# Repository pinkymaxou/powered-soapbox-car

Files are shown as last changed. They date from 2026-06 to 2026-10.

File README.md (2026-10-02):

# Powered Soapbox Car — 2-Seat Electric Kart for Kids




Project to build a **two-seat electric kart** for kids (~10 years old, 1.38–1.45 m), designed to be buildable with **basic tools** (drill, saw, wrenches) plus a **3D printer** for the gearboxes. Every choice is explained so you can adapt it to the materials you have on hand.

> **Note:** this kart is a **REVERSED tricycle**. The **2 REAR wheels are powered and independent** (one **12 V DC motor + gearbox + #35 chain per wheel**), sitting **under the bench**; **steering is done by the speed difference** between them (*differential / skid steer*) — **no steering wheel, no column, no linkage**. At the **front centre**, **one free 10″ caster** orients itself, with the battery in the nose over it → **3 wheels total**. ⚠️ The first version had this backwards (driven wheels at the front, caster at the rear, bench far from the driven axle) and it was **too unstable — 0.39 g**, held upright by the software turn limiter alone. A tricycle tips about the line from the **single** wheel to one of the **paired** wheels, so the usable half-track is `(distance CG→single wheel)/wheelbase`: putting the mass near the **paired axle** takes that from 45 % to 80 %. ⚠️ On **2026-08-10** the bench moved **6″ forward** and the axle **6″ back** — 12″ of separation — which gave back 78 mm of that: **61 %, a_tip 0.53 g**. That is still 1.4× the original tricycle — and since **2026-09-29 there is no software turn limiter at all** (the wheel sensors are gone; the owner's decision). In simulation a full-speed full turn at the default `duty_cap` 1.0 **tips the kart with one child sitting off-centre or with an adult aboard**; two children centred stay upright. `duty_cap` is the only lever — the numbers are in [§5](#5-critical-safety-points-child). The kart is a **two-seater** (two kids **side by side**) and **driven with a Bluetooth gamepad** ("arcade" mixing: one stick to go forward/back and to turn) — **no throttle pedal and no steering wheel**. Propulsion comes from the **2 rear motors**; there is **no** pedal crank and no chain.

## Table of contents

- [Overview (top view)](#overview-top-view)
- [At a glance](#at-a-glance) · [Why these choices](#why-these-choices)
- [1. Chassis dimensions](#1-chassis-dimensions)
- [2. Seat / controls position](#2-seat--controls-position)
- [3. Differential steering](#3-differential-steering-skid-steer) · [Driving: START arms, A drives](#driving-start-arms-a-drives)
- [4. Hardware & electronics](#4-hardware--electronics)
  - [Propulsion (2 rear motors)](#propulsion--2-rear-12-v-dc-motors) · [ESP32 control](#electronic-control--esp32) · [No wheel sensors](#no-wheel-sensors) · [Calibration](#gamepad-calibration)
  - [Electrical safety](#electrical-safety) · [Wiring & pinout](#wiring-diagram--esp32-pinout) · [System diagram](#full-system-diagram-all-connectors)
  - [The battery, unmeasured](#the-battery-unmeasured) · [2 batteries in parallel (dropped)](#wiring-2-batteries-in-parallel) · [Power switch (one main relay)](#power-switch-one-main-relay)
- [5. Critical safety points](#5-critical-safety-points-child)
- [6. Adjustable seat](#6-adjustable-seat)
- [7. Mass estimate](#7-mass-estimate)
- [8. Implementation plan (assembly & commissioning)](#8-implementation-plan-assembly--commissioning)
- [Firmware](#firmware) · [Known limitations and risks](#known-limitations-and-risks)

---

## Overview (top view)

```mermaid
flowchart TB
    subgraph AV["◄ FRONT ► — 1 FREE 10″ CASTER + battery over it"]
        direction LR
        AVG["🔋 12 V battery"]
        BAY["🛞 free caster 10″ (centred)"]
        AVD["🧠 ESP32 + driver"]
        AVG ~~~ BAY ~~~ AVD
    end
    subgraph CAB["CABIN — single 2-seat bench (~80 cm)"]
        direction LR
        COND["🧒 DRIVER (left)<br/>Bluetooth gamepad"]
        SEP["🛑 EMERGENCY STOP<br/>(top of seatback, centered)"]
        PASS["🧒 PASSENGER (right)<br/>footrest"]
        COND ~~~ SEP ~~~ PASS
    end
    subgraph AR["◄ REAR ► — 2 DRIVE wheels (under the bench)"]
        direction LR
        ARC["🛞 driven L (10″) — motor + gearbox + #35 chain<br/>🛞 driven R (10″) — idem"]
    end
    AV --> CAB --> AR

    classDef wheel fill:#cfe2ff,stroke:#333,stroke-width:2px;
    classDef caster fill:#e2e3e5,stroke:#333,stroke-width:2px;
    classDef drv fill:#d1e7dd,stroke:#333;
    classDef pas fill:#fff3cd,stroke:#333;
    classDef elec fill:#f8d7da,stroke:#333;
    classDef estop fill:#f8d7da,stroke:#900,stroke-width:2px;
    class AVG,AVD wheel;
    class ARC caster;
    class COND drv;
    class PASS pas;
    class BAY elec;
    class SEP estop;
```

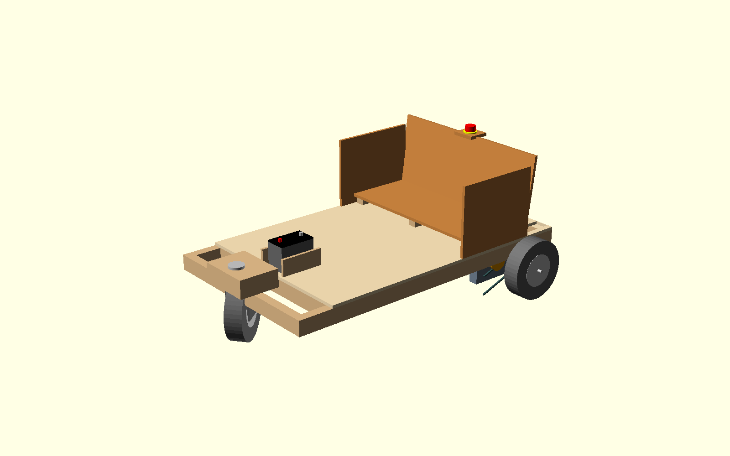
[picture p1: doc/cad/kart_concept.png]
3D concept of the kart


> Regenerable visual concept: [`doc/cad/kart_concept.scad`](doc/cad/kart_concept.scad) (OpenSCAD —
> the render command is in the file header). **Reversed tricycle, as built**: the free 10″ caster
> leads at the **front centre**, on a beam ~15 cm ahead of the deck, with the **12 V motorcycle
> battery in a retaining tray right above it** (the counterweight that keeps that single wheel
> planted); the **2 powered 10″ wheels are at the REAR**, each on its own motor + printed gearbox
> + #35 chain, axle 6″ behind the bench; 2-child bench, side guardrails, emergency stop at the
> top of the seatback, 2×3 frame + 1/2″ plywood.

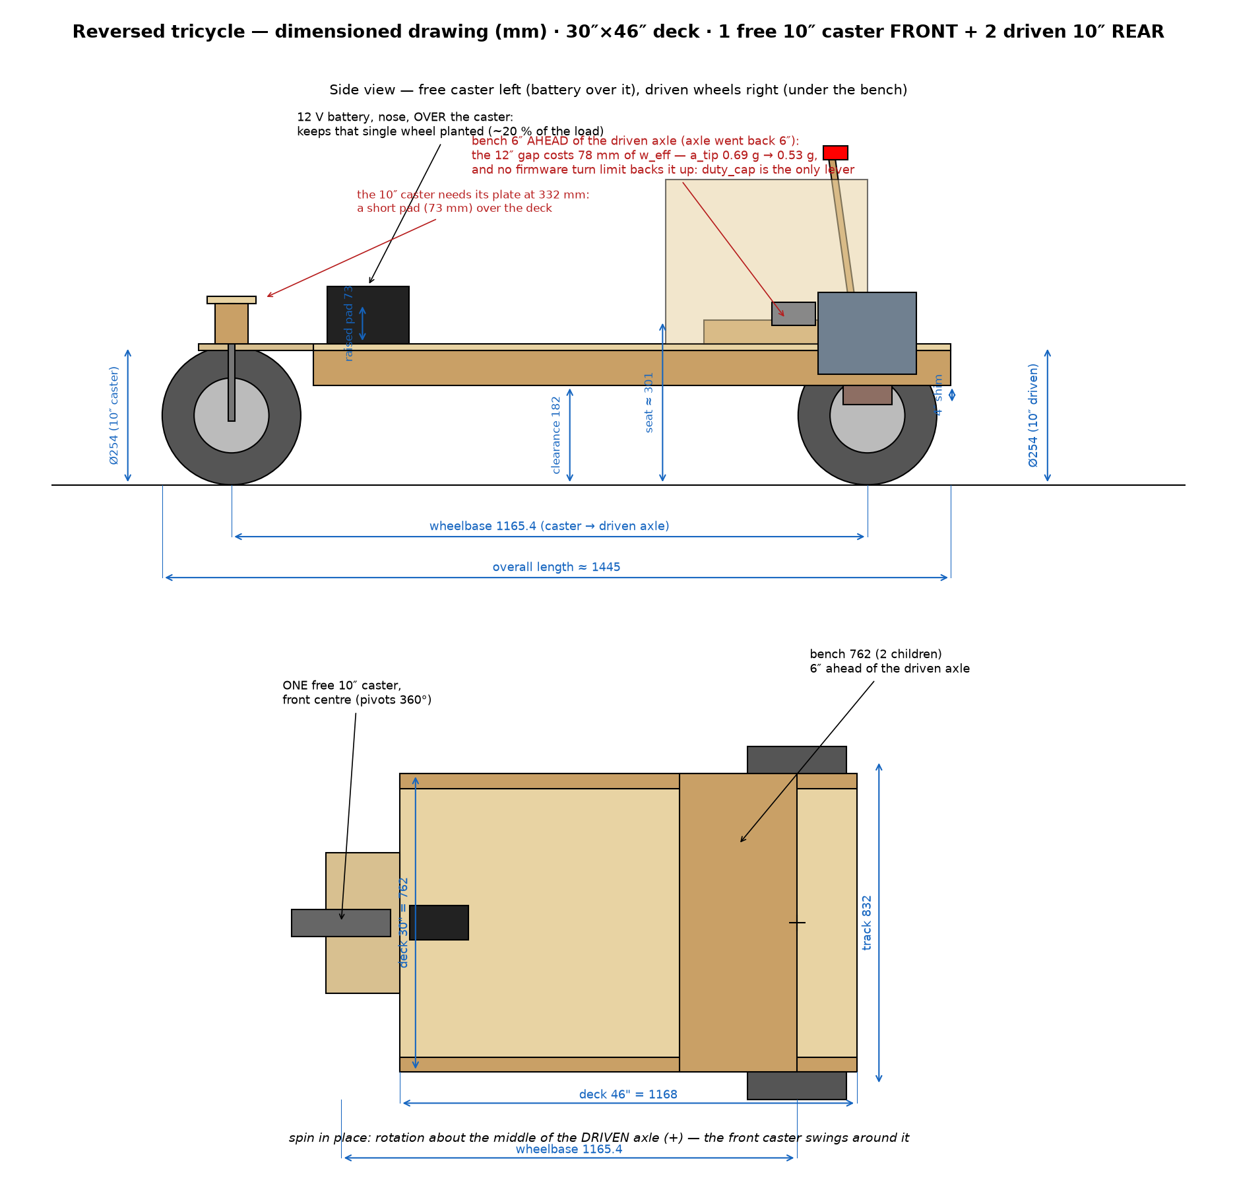
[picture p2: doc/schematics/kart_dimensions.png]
Dimensioned drawing of the kart


> Regenerable dimensioned drawing (mm): `python doc/schematics/kart_dimensions.py` — side and top
> views at the concept's dimensions.

**Footprint:** length ~145 cm · width ~90 cm · **track ~83 cm** · **wheelbase ~117 cm** · **2 rear drive wheels Ø25.4 cm (10″), 6″ behind the bench** + **1 free 10″ front caster (centred)** + battery and electronics in the nose · **side guardrails** + **emergency stop at the top of the seatback (centered)** · **a_tip ≈ 0.53 g**.

> ⚠️ For **flat ground, under adult supervision** only. Top speed **~9 km/h (~2.5 m/s, simulated)** since the 18T gearing of 2026-09-29, runtime ~10–20 min. **a_tip ≈ 0.53 g**. ⚠️ **There is no rollover protection**: nothing measures the speed, so nothing limits the turn. At the default `duty_cap` 1.0 a full-speed full turn tips the kart in simulation with one child off-centre or an adult aboard; `duty_cap` 0.9 keeps all three simulated loads upright ([§5](#5-critical-safety-points-child)).

## At a glance

| Item | Choice |
|---|---|
| **Seats** | 2, single bench side by side; **driver on the left** (gamepad) |
| **Steering** | **Differential (skid steer)**: speed difference between the 2 REAR driven wheels; **pivot in place** possible; **no mechanical steering parts** |
| **Propulsion** | **2× 12 V DC motors (~172 W / 0.23 HP)** at the REAR, **independent** (one per wheel) — **PWM/DIR per wheel** |
| **Transmission** | **3D-printed gearboxes** (16→80 then 30→80 = 1:13.33, 16T/24 DP motor pinion — see [`doc/reducteur.md`](doc/reducteur.md)) + **1.778:1 sprockets (18T→32T) bolted to the rear wheels + #35 chain** = **1:23.7 total** (25T / 1:17.07 until 2026-09-29 — the owner went to 18T to slow the kart down for the children) |
| **Wheels** | **2× rear drive Ø25.4 cm (10″)** (plastic rim, 1/2" bearing) + **1 free 10″ caster at the front centre** |
| **Driving** | **Bluetooth gamepad** (stick: Y = forward/reverse, X = turn); **hold A to drive — release A = brake**; **calibration mandatory**; analog joystick reserved (future) |
| **Electronics** | **ESP32** → **dual-channel driver 20 A / 6–30 V** (PWM + DIR / channel), PWM bounded by the manual `duty_cap` (the pack is always 12 V — the motors' nominal — so nothing is measured or capped automatically); **tech bay in the nose** (near the 2 motors, short power wiring) |
| **Power** | **One 12 V motorcycle battery**, **in the NOSE over the caster** — it keeps that single wheel planted (~20 % of the load). Single pack, no paralleling |
| **Speed** | **Not measured** — no wheel sensors since 2026-09-29. ~2.5 m/s top (simulated), bounded only by `duty_cap`; control loop at **500 Hz** |
| **Controls** | Driving with the **Bluetooth gamepad**; **arming** by holding its **START/Options** button ~1 s (no button on the kart), then **A held + stick = drive, A released = brake**; **main switch** (dash) powers the kart; **hardware emergency stop** at the **top of the seatback, centered** (breaks the main relay's COIL — thin wires, ~10-20 ms — and cuts the whole kart, so it does **not** brake: the kart coasts; reachable by both kids and by an adult behind) **+** software emergency stop = gamepad button **B** (this one brakes); **electric brake by default** |
| **Frame** | Lightweight **wood**: **2×3** studs + **6 mm plywood** floor |
| **Mass** | ~**32 kg** empty · ~**98 kg** loaded (2 kids) |
| **Rollover** | **a_tip ≈ 0.53 g** — the bench sits 6″ ahead of the paired (driven) axle, which keeps 61 % of the half-track in the tip triangle (it was 80 % when the two were coincident). ⚠️ **No software protection**: a full-speed full turn at `duty_cap` 1.0 **tips** in simulation with one child off-centre (−0.24 m/s²) or adult + child (−0.07); two children centred keep +1.62. `duty_cap` 0.9 keeps all three upright |

## Why these choices

- **Differential steering = zero mechanics**: no more steering wheel, column, kingpins, steering knuckles, tie rod or drag link → fewer parts to make, adjust and wear out; you **turn in software** (PWM difference between the 2 wheels). **Pivot in place** when forward motion ≈ 0.
- **One free caster at the front centre, mass toward the rear axle**: the caster orients itself → no steering geometry, and the layout puts the CG **61 % of the way back from the single wheel**, which is what keeps the tip triangle usable. ⚠️ This is the whole design: **never move mass toward the caster**. The first version had the bench far from the driven axle and reached only 0.39 g; putting it *on* the axle gave 0.69 g; the 6″/6″ split of 2026-08-10 gave back a quarter of that, to 0.53 g. There is no margin left to spend. A three-point frame also never rocks on uneven ground, which a four-wheel version would.
- **Stability is the geometry's and `duty_cap`'s alone**: **a_tip ≈ 0.53 g** (a car is ~1.0 g). The firmware rollover protection went away with the wheel sensors on 2026-09-29 — the owner's decision, taken with the numbers in hand: at `duty_cap` 1.0 the reference full-speed full turn **tips** the kart in simulation with one child off-centre (−0.24 m/s²) or adult + child (−0.07), while two children centred stay upright (+1.62). `duty_cap` 0.9 keeps every simulated load upright (+0.44 at worst); 0.8 gives back roughly the margin the old protection had (+1.07). Full sweep in [§5](#5-critical-safety-points-child).
- **One battery voltage, and it is 12 V** (2026-09-20 simplification): the motors are 12 V, the pack is 12 V, and **nothing measures it** — no ADS1115, no divider, no low-voltage cutoff, no automatic `12 V / Vbat` cap. The driver would accept 6–30 V, but running anything above 12 V would now need that cap back, so **do not**. The only power ceiling left is the manual **`duty_cap`** on the config page, which doubles as the "make it gentler for a small child" knob. The trade, stated: a flat pack is no longer reported, warned about or protected against — it just makes the kart slower. Charge it on a schedule and watch its own indicator.
- **Independently-mounted rear wheels**: driven by **#35 chain** (sprocket bolted to the rim), each keeps its original bearing on its own shoulder bolt — no through drive axle.
- **Battery and electronics in the nose, drive at the rear**: longitudinal layout **CASTER + BATTERY + ESP32 + driver (nose) → CABIN → BENCH → DRIVEN AXLE 6″ behind it**. The children sit just ahead of the driven wheels, which puts **~61 % of the load on them** — traction and electric braking both act there, and weight transfer on a slope works with you. It was 79 % before the 6″/6″ move; that 18 points is the same thing the rollover margin lost. The battery in the nose keeps the caster planted. Power runs nose→rear in 10 AWG (~0.3 V at 40 A).
- **Safety**: **central hardware emergency stop**, at the **top of the seatback** (within reach of both kids and an adult behind), **in the MAIN RELAY's coil loop together with the main switch** — the mushroom breaks ~150 mA, the relay contact breaks the 40 A, and **the whole kart goes dark, ESP32 included**. ⚠️ That means **no braking after the cut**: the kart coasts (~11 m from full speed on the flat, measured in simulation — do not use the mushroom as a brake, and never rely on it downhill). The **brake** is releasing **A**; the **software** emergency stop (gamepad button B) brakes properly because the firmware is still alive. Plus: one 40 A fuse, **two 1N4007 on the relay coil** — one **in series** (the coil energizes in one polarity only, so the relay is a **polarity gate** in front of the whole kart) and one **across** it (flyback for the two switches), **electric brake by default** (gamepad disconnect → immediate braking), **2 s watchdog (PANIC)**, **disarmed** start by default, guards over chains/sprockets, seatbelt, helmet.

---

## 1. Chassis dimensions

| Dimension | Value | Why |
|---|---|---|
| Total length | **~145 cm** | **30″ × 46″ platform** (762 × 1168 mm) + a **150 mm caster beam** ahead of its front edge. Unchanged by the 6″/6″ move — the deck never moved, only the axle and the bench inside it |
| Overall width | **~90 cm** (deck 30″ = 762 mm + the wheels) | The **30″ deck** sets everything: two kids side by side, and the track |
| **Bench inner width** | **76 cm** (the deck's width) | 2 × ~38 cm/child — the 30″ cut's cost, still workable |
| **Side guardrails** (1/2″ plywood, on each side of the bench) | height **~30 cm** above the floor, length ~40 cm | Keep the child from **falling out sideways**; rounded edges |
| **Tech bay** (nose, **over the caster**) | length ~**30 cm** | Houses the **battery** (strapped, in a tray over the caster), the driver, the ESP32 and the breakout. Motor wiring runs nose→rear in 10 AWG |
| **Track** (driven-wheel spacing, center to center) | **83.2 cm** = deck width + wheel width | The driven wheels sit in **notches cut in the deck** and bear laterally on the two **inboard 2×3 rails**, so the deck sets the track. This is the raw material of the rollover margin — the layout then decides how much of it survives |
| **Wheelbase** (caster axle ↔ driven axle) | **116.5 cm** (the axle moved back 6″ on 2026-08-10; the deck did not move) | Enters the rollover criterion directly: `w_eff = (track/2)·(1 − x_cg/wheelbase)` with **x_cg measured from the driven axle**. Here x_cg ≈ 46 cm → **61 %** of the half-track survives (254 mm of 416). It also sets the pivot envelope and the load split (≈61 % on the driven wheels) |
| Seat height (ground → seat bottom) | **~26 cm** | The deck rides **4″ above the driven axle on shims** and the 10″ wheels poke up through side notches beside it. Height is the other half of `a_tip ∝ 1/h_cg` — don't add cushions or a raised bench |
| Ground clearance (under frame) | **18 cm** | Consequence of the 4″ axle drop (underside of the 2×3 rails) |
| Seatback height (seat → top) | **34 cm** | Supports both kids' backs |
| **Rear drive wheels (×2 identical)** | **Ø25.4 cm (10″)**, plastic rim + hard PVC tire | Same wheels left/right, and the same 10″ as the caster → one wheel type for the whole kart |
| **Front caster wheel (×1)** | **10″ (Ø25.4 cm) on a pivoting fork**, centred, mounting plate at ~33 cm, load ≥ 50 kg | Unpowered, orients freely (360°). Carries only ~20 % of the load — the battery sits over it to keep it planted. Its plate needs **332 mm**, i.e. a short **73 mm pad** over the deck |
| **Axle length budget** | **85 mm of rod per wheel** (hub + washers + lock-nut), measured | One **1/2″ × 36″** rod (914 mm) covers both: 832 track leaves 41 mm of overhang per side for the 35 mm of hardware — ~6 mm of thread past the nylock |
| Hub / front-wheel mounting | **Metal bearing, 1/2" bore**, wide hub ~3.8 cm | Turns **free** on a **through dead axle: 1/2″ × 36″ threaded rod** (grade **8.8/B7**, hardware-store), **locknuts + washers at each end**, spacers to fix the lateral position (chain alignment), frame supports as close as possible to the hubs (≤ 3–5 cm, flex) |

**Guiding idea:** the mass goes **toward the paired axle**, and the single wheel goes at the far end carrying as little as possible. That rule took the same three wheels from 0.39 g to 0.69 g — and the 6″/6″ move of 2026-08-10 spent a quarter of it back, down to 0.53 g. Everything else still follows from it: battery in the nose over the caster, deck as low as the wheels allow, nothing heavy forward of the bench. Since 2026-09-29 no firmware limit backs the geometry up: `duty_cap` is the only lever (§5), the binding case being one child sitting off-centre.

> **Track / body decoupling**: the cabin doesn't need to be as wide as the track —
> a **T** frame: a **wide front crossmember** carrying the **axle bearings as close as possible to
> the wheels** (≤ 3–5 cm, otherwise the threaded rod flexes), narrow rails behind. The space along
> the axle between rail and wheel houses the **motor + gearbox + #35 chain** on each
> side. ⚠️ There is no firmware rollover protection to re-tune: if the geometry changes, update
> `VehicleParams` and re-run the simulation's `duty_cap` sweep (`firmware/test_host/run_sim.sh`) before driving.

---

## 2. Seat / controls position

Reference 0 = **caster axle** (front centre); dimensions measured **toward the rear**. The **tech bay** (battery + electronics) occupies the **nose, over the caster** — the one place where mass costs nothing, since it is the far end of the tip triangle.

| Item | Distance from the caster | Height / ground |
|---|---|---|
| Caster axle (reference) | **0 cm** | center at 12.7 cm (Ø25.4 caster) |
| **Battery + tech bay** | **~2–33 cm** | on the deck, low, strapped down |
| Deck front edge | **15 cm** | the caster hangs on a 15 cm beam ahead of it |
| **Footrest** | **~30 cm** | on the deck |
| Front of the seat | **~87 cm** | seat at ~29 cm |
| **Back of the seatback** | **~115 cm** | 6″ ahead of the driven axle |
| **Driven axle** | **116.5 cm** | 10″ wheels (Ø25.4), **4″ shims**; they sit in notches **behind** the bench, so the seatback clears them |

➡️ With the **Bluetooth gamepad**, there's **no more pedal box or steering wheel** to position: only seating ergonomics matter. **Seatback → footrest ≈ 57 cm** ✔ leg almost straight, slight knee bend. ⚠️ The bench sits **6″ ahead of the driven axle** and the deck has ~15 cm of free length behind it: that space is the wheels' and the drive stack's, and moving the bench any further forward costs rollover margin directly (`w_eff ∝ 1 − x_cg/wheelbase`). Provide a safe place to **rest/charge the gamepad**. **Adjustable** seat (§6) to fit the child's size.

➡️ **Emergency stop at the top of the seatback (centered)**: the **hardware mushroom button** (in series with the **main relay's coil**, together with the main switch) is mounted **at the top of the seatback, in the center** — reachable by **both kids** and by an **adult following the kart**. It **opens the main relay** (~10-20 ms, thin wires only) and **everything stops being powered: motors and ESP32 together**. ⚠️ Nothing brakes afterwards — the kart **coasts** (~11 m from full speed on the flat, and it does not stop at all on a slope). The **software** emergency stop on the gamepad (button **B**) is the one that brakes, because the firmware survives it; the mushroom is the last resort for "make it all stop being powered, now". Power returns on the main switch and the kart boots **disarmed**. **Side guardrails** on each side of the bench (no central divider: continuous bench). **Driving stays on the Bluetooth gamepad**.

> ⚠️ **Power off = coasting, and that now includes the e-stop.** Dynamic braking works by
> closing the driver's **low-side** MOSFETs, which needs gate drive — i.e. power. The old
> two-rail wiring kept the driver's logic alive through an e-stop so the brake probably
> survived it; with a single relay it does not. Cutting power (main switch, mushroom, blown
> fuse, or a relay released mid-reboot) opens every switch: **no electric brake**, only the
> passive drag of the 1:23.7 drivetrain — effective on the flat (the kart coasts ~11 m from full
> speed and stops), **insufficient on a slope** (the `coupure_pente8/16` scenarios reach 4.5 and
> 10.9 m/s eight seconds after the cut). That is the price of the single-relay simplification,
> and it is why the mushroom is documented as a last resort rather than a brake.
> Fail-safe remedy if ever needed: a **normally-closed-contact relay across each motor**
> (coil on the switched rail) — any power loss re-closes the contacts → automatic dynamic
> braking, no electronics.

### Side view

```mermaid
flowchart LR
    BAY["🧠 Nose: tech bay<br/>(ESP32 + driver) — ~−30–0 cm"]
    AV["🛞 Free 10″ caster (front centre)<br/>0 cm"]
    ASS["Front of seat<br/>~32 cm"]
    DOS["Seatback<br/>~62 cm"]
    AR["🛞 Driven wheels ~117 cm<br/>Ø25.4 cm, 6″ behind the bench"]

    BAY --> AV --> ASS --> DOS --> AR

    classDef axe fill:#cfe2ff,stroke:#333,stroke-width:2px;
    classDef caster fill:#e2e3e5,stroke:#333,stroke-width:2px;
    classDef ergo fill:#fff3cd,stroke:#333;
    classDef elec fill:#f8d7da,stroke:#333;
    class AV axe;
    class AR caster;
    class ASS,DOS ergo;
    class BAY elec;
```

> **Single 2-seat bench**: the two kids side by side (~80 cm inner), same seatback. The **driver (left)** holds the **gamepad**; the right side is passenger. The **tech bay** (electronics) is **in the nose**; the battery sits there too, in its tray above the caster.

### Top view (2-seat layout)

```mermaid
flowchart TB
    subgraph AV["FRONT — 2 DRIVE wheels + TECH BAY"]
        RAVG["🛞 rear left (drive)"]
        BAY["🧠 tech bay<br/>driver + ESP32"]
        RAVD["🛞 rear right (drive)"]
        RAVG --- BAY --- RAVD
    end
    subgraph HAB["CABIN — single bench ~80 cm"]
        COND["🧒 DRIVER (left)<br/>Bluetooth gamepad"]
        SEP["🛑 EMERGENCY STOP<br/>(top of seatback, centered)"]
        PASS["🧒 PASSENGER (right)<br/>footrest"]
        COND --- SEP --- PASS
    end
    subgraph AR["REAR — 2 DRIVE wheels"]
        RARC["🛞 driven L + R (10″)<br/>under the bench"]
    end
    AV --- HAB --- AR

    classDef wheel fill:#cfe2ff,stroke:#333,stroke-width:2px;
    classDef caster fill:#e2e3e5,stroke:#333,stroke-width:2px;
    classDef drv fill:#d1e7dd,stroke:#333;
    classDef pas fill:#fff3cd,stroke:#333;
    classDef elec fill:#f8d7da,stroke:#333;
    classDef estop fill:#f8d7da,stroke:#900,stroke-width:2px;
    class RAVG,RAVD wheel;
    class RARC caster;
    class COND drv;
    class PASS pas;
    class BAY elec;
    class SEP estop;
```

---

## 3. Differential steering (skid steer)

### Principle: **turn by speed difference between the 2 rear wheels**

There are **no mechanical steering parts**: no steering wheel, no column, no wheel kingpins, no steering knuckles, no tie rod, no drag link, no Pitman arm, no steering stops. **You turn by making one rear wheel roll faster than the other.** The **front wheel is a free caster** that follows the motion.

```mermaid
flowchart TD
    PAD["🎮 Bluetooth gamepad<br/>stick Y = forward · stick X = turn<br/>hold A to drive"]
    MIX["'arcade' mixing (firmware)<br/>left = forward + turn·gain<br/>right = forward − turn·gain"]
    LIM["duty_cap — the only limit<br/>(A released → brake)"]
    ML["⚙️ Rear left motor"]
    MR["⚙️ Rear right motor"]
    RG["🛞 Rear left wheel"]
    RD["🛞 Rear right wheel"]
    CAS["🛞 Free front caster (10″)<br/>(orients itself)"]

    PAD --> MIX --> LIM
    LIM -- "left command" --> ML --> RG
    LIM -- "right command" --> MR --> RD
    RG -. "the frame pivots" .-> CAS
    RD -. "the frame pivots" .-> CAS

    classDef cmd fill:#d1e7dd,stroke:#333;
    classDef mobile fill:#cfe2ff,stroke:#333,stroke-width:2px;
    classDef caster fill:#e2e3e5,stroke:#333,stroke-width:2px;
    class PAD,MIX,LIM cmd;
    class RG,RD mobile;
    class CAS caster;
```

1. **"Arcade" mixing**: the firmware combines forward motion (stick Y) and turn (stick X) into two wheel commands: `left = forward + turn·gain` and `right = forward − turn·gain`. Push the stick right = left wheel faster → the kart turns right.
2. **Pivot in place**: if forward motion ≈ 0 and you push the stick sideways, the two wheels turn **in opposite directions** → the kart **spins on itself** (the front caster swivels to follow).
3. **No rollover protection, no turn smoothing** (removed 2026-09-29 with the wheel sensors — a speed-dependent turn limit needs a measured speed): the mixed stick goes straight to the motors, bounded only by `duty_cap`. A full turn at full speed is allowed, and at `duty_cap` 1.0 it tips an off-centre load in simulation — numbers in [§5](#5-critical-safety-points-child). The only softening left is the **mixing curve** (`mix_type` 1 = expo: gentle around the centre, full authority at the stops). **Reverse** is as fast as forward (~2.5 m/s simulated) — there is no separate reverse limit any more.

Web parameters: **`duty_cap`** (the only limit), **`turn_gain`** (turn authority), and the **Drive feel** group (`mix_type` 0 linear / 1 expo, `mix_expo_fwd`, `mix_expo_turn`, `accel_pct_s`, `decel_pct_s`). Details in [`firmware/README.md`](firmware/README.md).

> **Consequence of skid steer:** in a tight turn, the wheels **scrub** slightly on the ground (sliding friction) — that's inherent to this type of steering. At moderate speed on flat ground, the effect stays acceptable. ⚠️ Do not count on the hard tyres sliding before the kart tips: nothing limits the turn any more, and the simulation does not model lateral grip.

### Driving: START arms, A drives

| Gamepad | Kart |
|---|---|
| **START/Options** held ~1 s, stick centred | **arms** (soft rumble). Disarmed = braking, whatever else is pressed |
| **A held + stick** | the mixed stick goes to the motors, bounded only by `duty_cap` |
| **A held, stick centred** | **pseudo-freewheel**: the target becomes 0 and the command slides there at `decel_pct_s` (default 100 %/s = one second from full PWM; 0 = straight to the brake) |
| **A released** | **dynamic brake** (motor short-circuit), **whatever the stick says** — this is the brake |
| **B** | emergency stop: disarm + brake (strong rumble) |
| stick pushed while **not armed** | strong rumble, repeated — the only "you can't drive" buzz; releasing A while armed does not buzz |

A is Bluepad32's `BUTTON_A` (mask 0x01) — the button the page's **Gamepad** tab lights as "A", whatever is printed on it. From full speed (simulated): releasing **A** leaves ~0.64 m/s one second later, then the kart stops; releasing the **stick** with A held leaves ~2.42 m/s after the same second. Also: gamepad silent **750 ms** (heartbeat) or disconnected → disarm + brake; not calibrated → will not arm; armed without driving for `disarm_s` (30 s) → disarm.

**Why "pseudo"-freewheel.** The Cytron MDD20A driver has **no coast state** in PWM/DIR mode: its truth table ([manual](doc/datasheet/motor-driver-20A-manual.pdf), Table 3, printed p. 3) puts both outputs low whenever PWM is low, whatever DIR — and both outputs low **is** the brake. So the firmware imitates a freewheel: the PWM runs down from where it was at the pace a coasting kart slows down, and the motor neither pushes nor brakes much on the way. Since 2026-09-30 that slide is a **rate in %/s**, not a duration: a run-down *is* a deceleration, so it shares one setting with the acceleration ramp instead of duplicating it in another unit. The old 10 s default (matched to a true coast) was far longer than anyone expects between centring the stick and stopping; 100 %/s = 1 s. Once the PWM reaches 0 it is electrically the brake, and the page says so. It is matched to the flat — nothing measures a slope. ⚠️ The old "freewheel" setting (`dyn_brake_en` = 0) **never freewheeled on this driver**: it put the same PWM-low state on the outputs, i.e. it braked.

---

## 4. Hardware & electronics

> **Mostly wooden, lightweight frame**: a grid of **2×3 studs** (SPF ~38×64 mm) + **6 mm plywood floor**. Reinforce at load points (rear motor mounts, front caster pad, seatbelt anchor). ⚠️ The 6 mm plywood requires a **closely-spaced 2×3 grid** (crossmembers every ~25–30 cm); **12 mm under the bench**.

| Category | Item | Size / spec |
|---|---|---|
| **Wood** | Frame (rails + crossmembers) | **2×3** studs (SPF ~38×64 mm), closely-spaced grid |
| | Floor | **6 mm** plywood, ~140 × 90 cm, supported by the grid |
| | Seat (loaded zone) | **12 mm** plywood under the bench |
| | Rear motor mounts / seatback | Hardwood block + plate; seatback in 6 mm plywood |
| **Wheels** | **2× rear drive wheels** identical | **Ø25.4 cm (10″)**, plastic rim + PVC tire, 1/2" bearing |
| | **1× pivoting FRONT caster wheel** | **Free**, unpowered; **Ø 25.4 cm (10")**, plate at ~33 cm, **load ≥ 50 kg** |
| | Shoulder bolts (driven wheels) | **Supplied with the wheels** (1/2" shoulder, 3/8" thread) |
| **Propulsion** | **2× 12 V DC motors** (one per **rear** wheel) | ~172 W (0.23 HP), 19.6 A, 4615 rpm; **independent** |
| | 2 3D gearboxes | **1:13.33** (16→80 then 30→80, [design](doc/reducteur.md)) + 1.778:1 sprockets = **1:23.7 total**, printed (PETG/ABS/nylon) |
| | Sprockets + #35 chain | Sprocket **bolted to each rear (driven) wheel** + #35 roller chain from the gearbox (**18T→32T = 1.778:1**; 25T→32T until 2026-09-29). Chain rather than a belt: **it can be cut to any length**, so the gearbox-to-wheel centre distance is free instead of being dictated by stock belt lengths. |
| **Driving** | **Bluetooth gamepad** | stick: Y = forward/reverse, X = turn; button **A** = hold to drive (released = brake), button **B** = emergency stop, button **START** = arming; **calibration mandatory** |
| | *Analog joystick* | **possible future**, behind the same software abstraction — but it would now need an ADC of its own (the ADS1115 and its two reserved channels are gone) |
| **Power / electronics** | Battery | **One 12 V motorcycle battery** (~40 A peak OK, PWM ~100%) **in the NOSE, strapped in a retaining tray above the front caster** — it is the counterweight that keeps that single wheel planted. No paralleling this phase. **12 V is now a design constant**: nothing measures the pack, so nothing could cap the duty for a higher-voltage one — the 24 V option went away with the ADC |
| | **Battery adapters** (×2) | Slide-on holder → power terminals (+ / −) |
| | **40 A automotive relay** + **2× 1N4007** on its coil | **the** main power switch: contact 30→87 carries the whole kart (see [power switch](#power-switch-one-main-relay)) + 1 fuse. One diode **in series** in the coil loop makes the relay a **polarity gate** (reversed battery ⇒ the coil never pulls in ⇒ nothing downstream is powered); the other, **across** the coil, is the flyback for the two switches |
| | **Main switch + e-stop mushroom** | both **in series in the relay's coil** (~150 mA, thin wire): the main switch on the dash is the kart's on/off, the mushroom at the top of the seatback is the emergency cut. No latch, no priming button, no FORCE ON toggle, no hold capacitor. Full BOM: [`doc/electronique.md`](doc/electronique.md) |
| | Motor driver | **1 dual-channel board 20 A / 6–30 V** (PWM+DIR/channel), duty bounded by the manual cap `duty_cap` |
| | Controller | **ESP32-WROOM board** (dual-core 240 MHz, Wi-Fi/BT, 4 MB flash) |
| | **Breakout board** | Screw terminals + 5 V / 3.3 V outputs + status LED |
| | **Buck → 5 V** (20 V-rated unit already on hand, fed from the switched 12 V rail) | powers the ESP32 (which makes its own 3.3 V) |
| | **Soldered perfboard** | connectors + the WS2812's series resistor (⚠️ no breadboard — vibration). The I²C pull-ups and the Vbat divider that used to live here are gone |
| | **Weatherproof electrical enclosure** (ABS, clear lid, ~150 × 100 × 70 mm, ≈IP65) | **in the front tech bay**; houses ESP32 + breakout + perfboard; cable glands for the cables; protects against dust/rain/impact (clear lid = status LED visible) |
| | Elec. safety | **Emergency stop (NC) in series in the relay coil** (mushroom button **at the top of the seatback, centered**, within reach of both kids) + **main switch** in the same loop + **fuse** |
| | **WS2812B** strip (~10 LEDs) | status: **moving rainbow = armed & ready**, yellow = disarmed (pulsing while arming), blinking red = gamepad connected but **not calibrated** (START does nothing until it is), blue = calibration in progress |
| **Controls** | **Arming** | ~1 s press on the **gamepad's START/Options** button, stick centered — no button on the kart itself |
| **Brake** | **Electric brake (default)** ✅ | **A released = dynamic brake** (the driver grounds both motor terminals); **default state = braking**; gamepad disconnect → immediate braking; no brake pad. Stick pulled back with A held = plugging (reverse torque) |
| **Future reserves** | **analog joystick** | would need its own ADC now, plus 2 free GPIOs — 13, 14, 16, 18, 19, 21, 22, 23 and 27 are available |
| **Fasteners / finish** | M8/M10 through-bolts, **nylock** nuts | brackets, wood screws, varnish; rounded edges |

### Propulsion — 2 rear 12 V DC motors

Each **rear wheel** is driven by its **own 12 V permanent-magnet DC motor** through a **3D-printed 1:13.33 gearbox** (16→80, 30→80) and an **18T→32T #35 chain (1.778:1)** — total reduction **1:23.70**. It was 25T / 1:17.07 until **2026-09-29**, when the owner fitted the 18T to slow the kart down for the children: top speed **×0.72**, wheel torque **×1.39**. The **two motors are controlled independently** (PWM + DIR per channel): it's this **command difference** that provides steering. **Nothing measures the wheels** — stick → PWM, open loop.

| Characteristic | Value |
|---|---|
| Type / model | **Permanent-magnet** DC — RX0086 |
| Power | **0.23 HP (~172 W)** |
| Speed | **4615 rpm** (at 12 V, no load) |
| Voltage / current | **12 VDC** / **19.6 A** |
| Duty | **intermittent** (leisure, not continuous); TENV, class F |

> ⚠️ **Voltage:** motors **12 V**, driver **6–30 V**, pack **12 V and only 12 V** — the two match, so there is nothing to cap automatically and nothing measures the battery. The manual `duty_cap` is the ceiling; a higher-voltage pack would cook the motors and is not an option any more.
> ⚠️ **Current:** **19.6 A**/motor (driver 20 A/channel OK); **total ~40 A** — carried by the **single pack**, not split across two. Size the fuse, the cable and the relay for the full 40 A, and expect the sag that goes with it (see [the battery](#the-battery-unmeasured)). Avoid prolonged wheel stalls.

```mermaid
flowchart LR
    BATT["🔋 12 V motorcycle battery"]
    PAD["🎮 Bluetooth gamepad"]
    ESP["🧠 ESP32<br/>(arcade mixing, A-button gate, duty_cap)"]
    DRV["Dual-channel driver<br/>20 A · 6–30 V · PWM+DIR"]
    M1["Rear L motor 12 V (~172 W)"]
    M2["Rear R motor 12 V (~172 W)"]
    G1["3D gearbox 1:13.33"]
    G2["3D gearbox 1:13.33"]
    R1["🛞 Rear left wheel"]
    R2["🛞 Rear right wheel"]
    CAS["🛞 Free front caster"]

    BATT -- "power supply" --> DRV
    PAD -. "Bluetooth (x,y)" .-> ESP
    ESP -- "PWM+DIR channel L (3.3 V)" --> DRV
    ESP -- "PWM+DIR channel R (3.3 V)" --> DRV
    DRV -- "channel L (≤20 A)" --> M1 --> G1 -- "18T→32T #35 chain (1.778:1)" --> R1
    DRV -- "channel R (≤20 A)" --> M2 --> G2 -- "18T→32T #35 chain (1.778:1)" --> R2
    R1 -. "the frame pivots" .-> CAS
    R2 -. "the frame pivots" .-> CAS

    classDef pwr fill:#f8d7da,stroke:#333;
    classDef ctrl fill:#d1e7dd,stroke:#333;
    classDef wheel fill:#cfe2ff,stroke:#333,stroke-width:2px;
    classDef caster fill:#e2e3e5,stroke:#333,stroke-width:2px;
    class BATT pwr;
    class ESP,DRV,PAD ctrl;
    class R1,R2 wheel;
    class CAS caster;
```

**Estimated performance:**

| Parameter | Value |
|---|---|
| Wheel speed at full PWM, no load | 4615 rpm ÷ 23.70 ≈ **195 rpm** → 2.6 m/s |
| Estimated top speed | **~2.5 m/s (~9 km/h)** loaded, simulated — bounded only by `duty_cap` (it was ~3.3 m/s with the 25T) |
| Total current | ~**40 A**, all from the single 12 V pack |
| Battery energy / runtime | ~90–100 Wh → **~10–20 min** depending on use |

**Transmission gearbox → wheel:** sprocket **bolted to the inner side of the wheel** (multiple spokes, large washers / backing plate so as not to crack the plastic), **18T→32T #35 sprockets = 1.778:1** (exact tooth ratio — see [`doc/reducteur.md`](doc/reducteur.md)) with tension adjustment (slotted holes / idler), **closed guard**. The wheel turns **free on the through axle**; the motor only drives it. **Measure the hub thickness before the final cut of the rod**; **adjustable spacers** to bring the wheel-sprocket plane in line with the gearbox sprocket (chain alignment = critical adjustment: a misaligned chain climbs a sprocket flank and is thrown), gearbox mounting with slotted holes for fine adjustment.

**Where to put the gearbox output sprocket** — full reasoning and the centre-distance table in
[`doc/reducteur.md`](doc/reducteur.md#where-to-put-the-gearbox-output-sprocket):

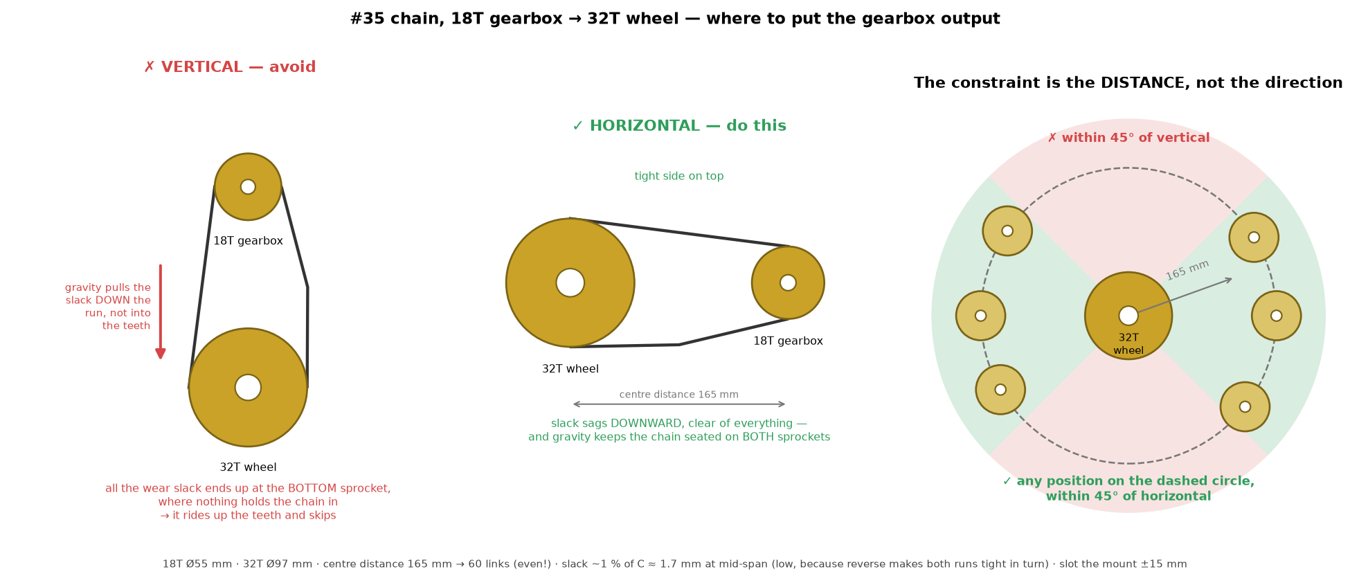
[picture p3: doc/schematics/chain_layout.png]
Chain layout


- ⚠️ **Never one sprocket directly above the other.** Gravity then pulls the slack *along* the run
  instead of into the teeth, and wear elongation all collects at the **bottom** sprocket where
  nothing keeps the chain seated — it climbs the teeth and skips. Keep the line of centres
  **within 45° of horizontal**.
- **The constraint is the DISTANCE, not the direction**: any position on a circle around the wheel
  axle works, as long as it avoids the two vertical 45° sectors. Useful freedom when a frame member
  is in the way — forward, back or diagonally up are all fine.
- **165 mm centre distance → 60 links** with the 18T (165.3 mm hits 60 exactly; it was 64 links
  with the 25T, and a 64-link chain on the 18T would need 184.5 mm). A short centre distance costs
  almost nothing at ~1.0 m/s and 15 % of working load; what it costs is **tension sensitivity**
  (1.7 mm of nominal slack), so expect to re-tension more often.
- **Even link count is mandatory** (an odd one needs a cranked link, ~20 % weaker), slack **~1 % of
  C** rather than the usual 2 % because reverse makes both runs tight in turn, and slot the mount
  **±15 mm**.

### Electronic control — ESP32

- The **ESP32** receives the **Bluetooth gamepad** axes and buttons, applies **arcade mixing** while **A is held**, then sends **an independent PWM + DIR to each channel** of the driver, bounded by `duty_cap`.
- Driver: **Cytron MDD20A — dual-channel, 20 A continuous / 60 A peak, 6–30 V**, **PWM + DIR** inputs compatible with **3.3 V**, PWM up to 20 kHz; **overcurrent / undervoltage / temperature** protections. ⚠️ **No reverse-polarity protection** (VB+/VB-) → a reversed connection **destroys the board**. ⚠️ **No coast state** in PWM/DIR mode: PWM low = both outputs low = brake, whatever DIR — hence the [pseudo-freewheel](#driving-start-arms-a-drives).
- **Dynamic brake by default**: A released, disarmed, gamepad lost, silent, uncalibrated or B pressed → PWM 0 + DIR low on both channels = both motor terminals grounded (short-circuit braking, force ∝ speed). This is the **default state**, from boot. No PID and no braking loop — nothing measures the wheels.
- Best practices: **manual PWM cap** (`duty_cap`), **expo mixing curves** for a gentle throttle (`mix_type`), **accel ramp** in %/s to spare the drivers the current step of a stick slammed open (`accel_pct_s`), **hold-to-drive A button**, **watchdog**, **braking if the gamepad disconnects**.

### No wheel sensors

**Nothing on this kart measures speed** (2026-09-29 simplification). The two **AS5600** angle
sensors, their magnets, their two I²C buses (GPIO 18/19 and 27/14, now free) and the 4.7 kΩ
pull-ups are gone, and with them everything that read them: the speed-limiter and braking PIDs,
the **rollover protection** (speed-dependent turn limit + turn slew rate), the speed-adaptive
mixer (`mix_type` 2), the reverse speed limit and the encoder conditions (stuck / reversed /
erratic / absent / magnet). What is left is **stick → PWM**, gated by A, bounded by `duty_cap`.

What that costs, plainly: no speed limit other than `duty_cap`, **no rollover protection**
([§5](#5-critical-safety-points-child)), no detection of a stalled wheel or a thrown chain, no
speed on the page. What it buys: no sensor to mount, align, wire or trust, and nothing that
stops the kart because a magnet moved.

### No faults

That last removal took the **fault layer** with it (2026-09-30). The firmware no longer has a
fault mask, a `Fault` enum, a fault state or a red "FAULT" badge: each sensor that could report
a breakage had already gone — the battery ADC, the relay-coil sense, the encoders — and what was
left were four ordinary gamepad conditions (**off · silent · B held · not calibrated**), none of
which is a failure. They still **disarm and brake**; the page and the event log now simply name
the one that applies (`enum class Stop`) instead of lighting up a fault. Retired bits, codes and
protobuf fields are **never reused**, so the event log written by an older firmware still decodes
to what it meant then.

### No analog measurements

**There is no ADC on this kart** (2026-09-20 simplification). The ADS1115, the 100 k / 15 k
divider and everything they fed — low-voltage cutoff, 12/24 V detection at boot, automatic
`12 V / measured Vbat` PWM cap, battery gauge and chart, `LVC` and `NO_VBAT` faults — were
removed together. The pack is **always 12 V**, which is the motors' nominal voltage, so the
measurement had nothing left to decide.

What replaces it: **nothing, deliberately.** The manual `duty_cap` is the power ceiling, the
battery's own indicator is the fuel gauge, and a worn pack shows up as a kart that feels
slower (simulated in `batterie_usee`: 11.2 V and 0.12 Ω of internal resistance still drive,
just less briskly, with no fault raised). Deep-discharge protection is the pack's business.

### Gamepad calibration

**The kart refuses to move until the gamepad is calibrated.** Calibration is done **exclusively from the web page** (Gamepad tab), **for the Bluetooth gamepad only**:

1. **Center**: stick at rest → captures the neutral point;
2. **Extremes**: move the sticks fully → captures the amplitude per axis.

The scale (center + half-amplitude per axis) is **persisted in NVS** (namespace `pad`). ⚠️ **(Re)pairing ERASES the calibration** (new gamepad = new calibration). Until the gamepad is calibrated, connected and armed — and A is held — the controller **stays braking** (default state).

### Electrical safety

- **Emergency stop** easily accessible, **in the main relay's coil loop** (in series with the main switch): pressing it de-energises the coil and the **relay contact breaks the 40 A** (~10-20 ms). The mushroom itself only switches ~150 mA on signal-gauge wires — no 40 A detour to the seatback, any decent NC mushroom qualifies. ⚠️ **It cuts the ESP32 too**, so the firmware never sees it: nothing reported, no log entry, and above all **no braking** — the kart coasts (~11 m from full speed on the flat; a slope is worse). Power returns on the main switch and the kart boots **disarmed**. A **welded contact** is no longer detectable in software either: the commissioning test (mushroom pressed, multimeter on VB+) is what catches it. In exchange the wiring lost a relay, an opto, a sense pin and every software path that went with them. The gamepad's **button B** remains the emergency stop that actually **brakes**, because the firmware survives it.
- **Main switch** (dash, in the same coil loop) is the kart's on/off — the only control on the vehicle. Arming is a gamepad button. **Fuse/pack**, wiring ≥ the 2 motors' current.
- **The relay is a polarity gate**: nothing is powered until the contact closes, and a **1N4007 in series** in the coil loop means the coil energizes in one polarity only. Connect the battery backwards and the coil simply does nothing — no current anywhere, nothing blown, nothing stressed; put it back the right way and the kart starts. A second 1N4007 **across** the coil is the flyback for the two mechanical switches. ⚠️ Neither one covers a VB+/VB− swap made *downstream* of the contact, at the driver's terminals.
- **Battery: one 12 V motorcycle battery** (lead-acid — no BMS of its own). ⚠️ **Deep-discharge protection is now the pack's alone**: the firmware LVC went away with the voltage measurement. The 40 A fuse still covers shorts. Charge on a schedule rather than on a warning.
- **One 12 V pack, no paralleling** (this phase): it carries the whole ~40 A, so its internal resistance sets the sag under load — a motorcycle battery at ~0.05 Ω dips ~2 V at full throttle, which the motors feel as a little less thrust. ⚠️ **Never put packs in series**: 24 V on 12 V motors, with no automatic cap left to hold the duty down, cooks them.
- **`duty_cap` low at first** (it is the only limit); **battery secured/protected**; **guards**; **electric brake** (A released) + **auto disarm** + **2 s watchdog**. Cut power before servicing (main switch, and pull the fuse for anything invasive).

### Wiring diagram + ESP32 pinout

```mermaid
flowchart LR
    BATT["🔋 1 pack 12 V<br/>(motorcycle battery)"]
    FUSE["Fuse 40 A"]
    COIL["🔑 MAIN SWITCH → 🛑 E-STOP (NC)<br/>in series, ~150 mA<br/>+ 1N4007 across the coil"]
    SW["🔌 MAIN RELAY 40 A<br/>contact 30→87 carries the WHOLE kart"]
    RAIL(["+12V_SW — the one switched rail"])
    GNDC(["Common GND"])
    BUCK["Buck<br/>12 V → 5 V"]
    ESP["🧠 ESP32"]
    PAD["🎮 BT gamepad"]
    DRV["Dual-channel driver<br/>20 A / 6–30 V"]
    M1["⚙️ Rear L motor 12 V"]
    M2["⚙️ Rear R motor 12 V"]
    WS["🌈 WS2812B strip"]

    %% Power: ONE relay, ONE rail — either switch in the coil kills everything
    BATT -- "+" --> FUSE --> SW
    FUSE -- "coil supply" --> COIL -- "coil 85/86" --> SW
    SW -- "+12V_SW (40 A)" --> RAIL
    RAIL -- "VB+ and board logic" --> DRV
    RAIL --> BUCK --> ESP
    BATT -- "−" --> GNDC
    DRV -- "GND" --> GNDC

    %% Motor outputs (no speed feedback: nothing measures the wheels)
    DRV -- "M1A / M1B" --> M1
    DRV -- "M2A / M2B" --> M2

    %% Signals
    PAD -. "Bluetooth" .-> ESP
    ESP -- "PWM+DIR L/R" --> DRV
    ESP -- "data GPIO4" --> WS

    classDef pwr fill:#f8d7da,stroke:#333;
    classDef ctrl fill:#d1e7dd,stroke:#333;
    classDef mot fill:#cfe2ff,stroke:#333,stroke-width:2px;
    class BATT,FUSE,RAIL,SW,COIL,BUCK pwr;
    class ESP,DRV,PAD ctrl;
    class M1,M2 mot;
```

**ESP32 pinout (identical to the firmware `firmware/main/pinout.hpp`):**

| GPIO | Function | Direction | Note |
|---|---|---|---|
| 26 / 25 | **PWM / DIR REAR left motor** | output | LEDC 18 kHz, duty ≤ `duty_cap` |
| 33 / 32 | **PWM / DIR REAR right motor** | output | same |
| 4 | **WS2812B strip** (data) | output | ~10 LEDs |
| 2 | **Status LED** (onboard) | output | — |
| **Free** | | | |
| 34 / 35 / 36 / 39 | unused | inputs only | input-only pins, **no internal pulls** |
| 13 / 14 / 16 / 18 / 19 / 21 / 22 / 23 / 27 | unused | — | free — **13** was `POWER_HOLD` (power latch), **22** `MOTOR_PWR_SENSE` (e-stop coil sense), **16** the arming button, **18/19** and **27/14** the two I²C buses of the wheel encoders (removed 2026-09-29). **No GPIO input is used at all**: the kart's only controls are the main switch, the mushroom and the gamepad |
| — | **Power on/off** | (no GPIO) | **hardware only**: main switch + e-stop in the relay coil. The firmware can neither hold nor cut its own supply |

> **Motor wiring corrections in software** (web page → Settings → Behavior), for when the
> motors are not wired as above: **`mot_inv_l` / `mot_inv_r`** flip one wheel's direction
> (= swapping that motor's two leads), **`mot_swap_lr`** sends the LEFT wheel's command to the
> RIGHT channel (GPIO 33/32) and vice versa (= motors on crossed driver channels: forward is
> right but the steering is mirrored). While any of them is set, the **Dashboard** and the
> **pinout** of the page show an amber banner: the wiring then does NOT match this table.
> Rewiring to match the table stays the cleaner fix.

**Key wiring points:**
- **Common ground** ESP32 ↔ driver: essential.
- **One rail**: the main relay's contact carries everything (buck → ESP32 + strip, driver VB+ *and* driver logic). Its coil runs through the **main switch** and the **e-stop mushroom** in series, with the **1N4007** across it. No GPIO is involved in powering the kart.
- **Brake by default**: A released, disarmed, or gamepad lost → the firmware brakes.
- **Power ~10 AWG** (crimped lugs); **signals thin wire**. **40 A fuse** on the single pack.
- ⚠️ **Driver polarity (VB+/VB-)**: the board has no reverse protection, and it sits **downstream of the relay contact**, where the coil diode cannot help → **double-check by hand**.
- **Nothing measures the battery** — no divider, no ADC (see [the battery](#the-battery-unmeasured)).

### Full system diagram (all connectors)

Block-by-block overview showing **each connector** (gamepad via the internal radio, rear motors, WS2812 — there are no sensors) and the **power supply** (one relay, one rail).

```mermaid
flowchart LR
    subgraph PWR["⚡ Power supply"]
        direction TB
        PA["🔌 PACK CONN<br/>12 V (+ / −)"] --> FA["Fuse 40 A"] --> BR["🔌 MAIN RELAY 40 A<br/>contact 30→87"]
        FA -->|"coil supply"| MSW["🔑 MAIN SWITCH"] --> ESTOP["🛑 E-STOP (NC)"] -->|"coil 85 (1N4007 across)"| BR
        BR --> RAIL(["+12V_SW — everything"])
        RAIL --> BUCK["Buck 12→5 V"] --> V5(["+5 V"])
    end

    ESP["🧠 ESP32-WROOM<br/>3.3 V via on-board regulator"]
    V5 --> ESP

    PAD["🎮 BLUETOOTH GAMEPAD<br/>(ESP32 internal radio)"] -.->|"x, y, buttons (A, B, START)"| ESP

    ESP -->|"PWM/DIR L+R<br/>GPIO26/25/33/32"| DRV["🛞 MOTOR DRIVER<br/>2 channels 20 A"]
    RAIL --> DRV
    DRV -->|"M1A / M1B"| MG["⚙️ REAR L MOTOR CONN"]
    DRV -->|"M2A / M2B"| MD["⚙️ REAR R MOTOR CONN"]
    ESP -->|"GPIO4 data"| WS["🌈 WS2812B CONN"]

    V5 -. "+5 V" .-> WS

    classDef pwr fill:#f8d7da,stroke:#333;
    classDef conn fill:#fff3cd,stroke:#333;
    class RAIL,V5,BR,MSW,ESTOP,DRV pwr;
    class PA,PAD,MG,MD,WS conn;
```

### Electrical schematic (symbols)

The same content as an **electrical schematic with standard symbols** (named-port style:
**net labels with the same name are connected**, as on a multi-sheet schematic):

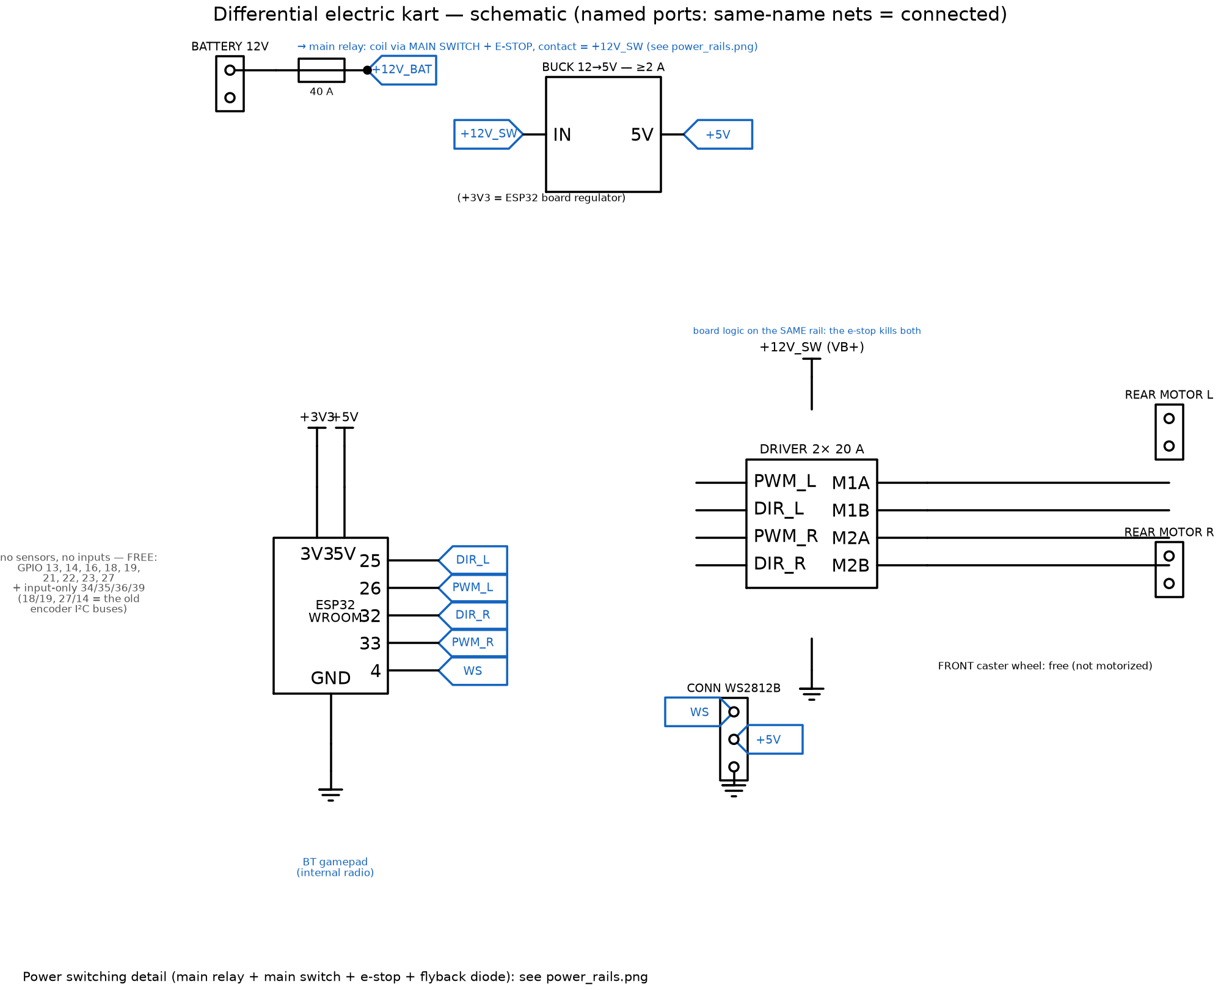
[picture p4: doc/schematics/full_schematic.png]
Electrical schematic of the kart


> Regenerable: `. .venv-schem/bin/activate && python doc/schematics/full_schematic.py`.
> The power-switching detail is in [`power_rails.png`](doc/schematics/power_rails.png).

### The battery, unmeasured

**Nothing on this kart measures the battery** — a deliberate removal (2026-09-20), together
with the ADS1115, the 100 k / 15 k divider, the low-voltage cutoff, the 12/24 V detection and
the automatic `12 V / Vbat` PWM cap. The pack is a **12 V motorcycle battery**, which is also
the motors' nominal voltage, so the measurement had nothing left to decide: the duty ceiling
is the manual `duty_cap`, and it does not depend on what the voltmeter says.

| What used to happen | What happens now |
|---|---|
| Voltage on the web gauge + 30 min chart | nothing — the gauge and the chart are gone |
| Warning at 11.5 V (orange LED strip) | nothing; the strip keeps its rainbow |
| Cutoff at 10.5 V: blocking fault, disarm, power cut after 30 s | nothing — the kart drives until the pack gives up |
| PWM capped at 12 V / measured Vbat (24 V pack → ~50 %) | manual `duty_cap` only; **do not fit a >12 V pack** |
| `LVC` and `NO_VBAT` faults, `vbat_check_en` setting | removed from the firmware, the page and the protocol |

**What you lose, plainly**: the kart will not warn you about a flat battery, will not refuse to
drive on one, and will not turn itself off to save one. Deep-discharge protection is the pack's
own business now. **What it feels like instead**: a worn pack sags under load, so the motors
see less voltage and the kart is simply **slower** — the `batterie_usee` simulation scenario
runs a 11.2 V / 0.12 Ω pack and confirms it drives, more feebly, with no fault raised.

**What to do about it**: charge on a schedule rather than on a warning, and read the charge on
the battery's own indicator, off the kart. A lead-acid pack that is regularly run flat dies
young — that is the risk this simplification accepts.

### Wiring 2 batteries in parallel

> ⛔ **Out of scope for this phase.** One **single 12 V pack**, no paralleling — so no
> diode-OR, no ideal-diode modules, nothing to arbitrate between sources. Kept below because
> the sizing holds if a second pack is ever added **in parallel** (same voltage). ⚠️ **In
> series is now out of the question**: 24 V on 12 V motors used to be held back by the
> automatic `12 V / Vbat` cap, and that cap went away with the voltage measurement.*

```mermaid
flowchart LR
    PA["🔋 Pack A<br/>20 V"]
    PB["🔋 Pack B<br/>20 V"]
    FA["Fuse A"]
    FB["Fuse B"]
    DA["Ideal diode A<br/>(MOSFET)"]
    DB["Ideal diode B<br/>(MOSFET)"]
    RAIL(["Common +20 V rail"])
    LOAD["To motor driver (+)<br/>and buck 20→5 V (ESP)"]

    PA --> FA --> DA --> RAIL
    PB --> FB --> DB --> RAIL
    RAIL --> LOAD
    PA -. "GND via low-side MOSFET" .- PB

    classDef pwr fill:#f8d7da,stroke:#333;
    class PA,PB,RAIL pwr;
```

**Diode-OR:** each pack supplies **through a diode** → no balancing current, you can clip on a slightly discharged pack safely. **Sizing:** ~40 A shared → ~**20 A/diode** → **40 A / 60 A modules** (low MOSFET drop vs ~8 W of losses with a Schottky). ⚠️ Without diode-OR, a ΔV > 2 V between packs = **dangerous spike**; in that case only connect packs **at the same voltage**.

### Power switch (one main relay)

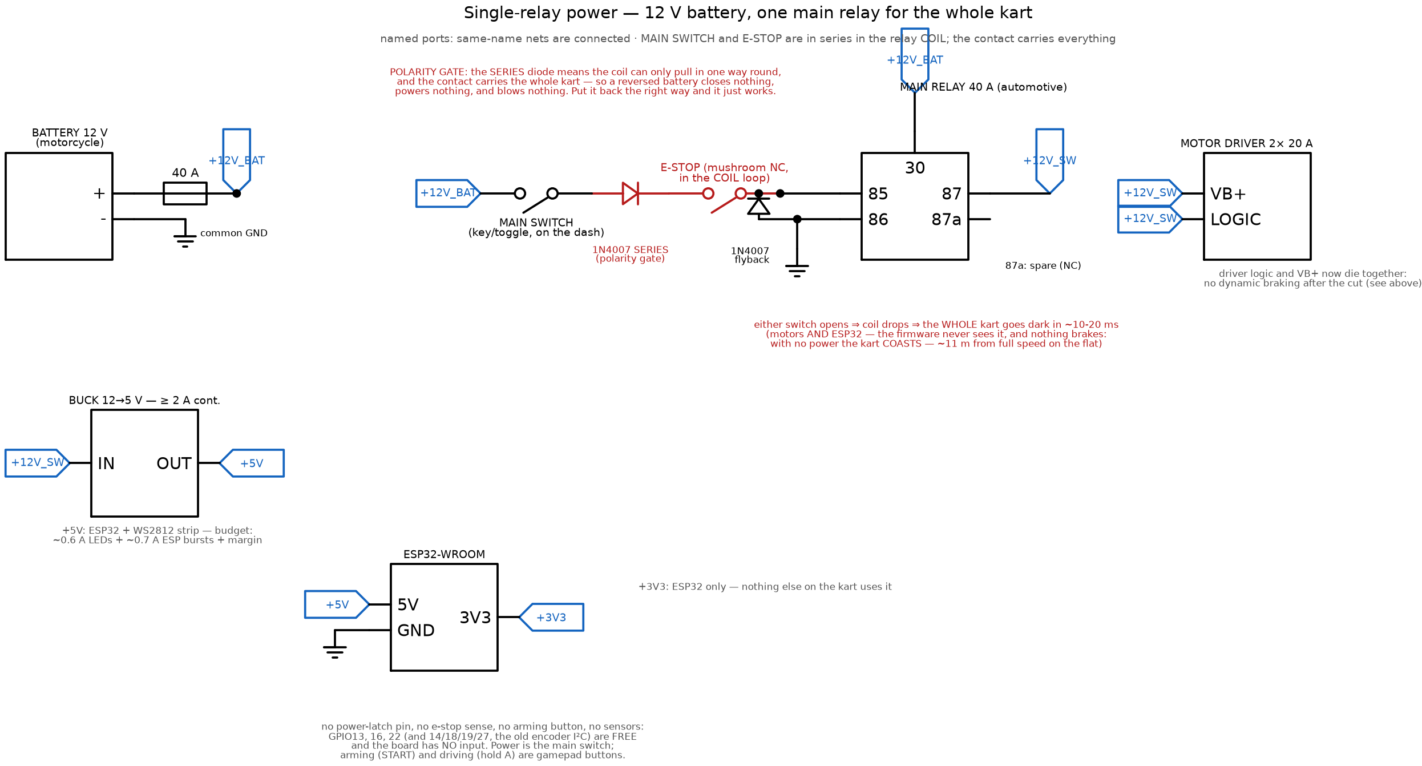
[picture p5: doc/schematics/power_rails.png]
Single-relay power schematic


> Full design rationale, BOM and the terminal-by-terminal wiring guide:
> **[`doc/electronique.md`](doc/electronique.md)**. Regenerable:
> `. .venv-schem/bin/activate && python doc/schematics/power_rails.py`.

> 🔁 **This phase: ONE relay, ONE rail.** The previous build had two (a small opto module
> holding a logic rail from `POWER_HOLD`, plus a 40 A relay for the motors) so that the brain
> could survive an emergency stop and *report* it. That reporting bought a fault message on a
> page nobody was looking at mid-drive — it never made the kart stop any harder — and it cost a
> second relay, an optocoupler, two GPIOs, a priming button, a hidden FORCE ON switch and a
> "reboot = power-down" rule. All of it is gone.
>
> **The chain, end to end:** fused battery + → **main switch** → **e-stop mushroom (NC)** →
> relay **coil** (85), coil → ground (86), **1N4007 across the coil, cathode to 85**. The
> **contact (30 → 87)** carries the whole kart: buck → 5 V (ESP32, WS2812) and the driver's
> **VB+ and logic** alike. Either switch opens ⇒ the coil drops ⇒ everything goes dark in the
> relay's own ~10–20 ms. **87a stays spare.**
>
> **What the e-stop costs now: the brake.** Dynamic braking shorts the windings through the
> driver's **low-side** MOSFETs, which need gate drive — i.e. power. With the two-rail wiring
> the driver's logic stayed alive through an e-stop, so the brake probably survived it (a
> bench test settled it either way). With one relay it does not survive: the mushroom removes
> the gate drive along with everything else, and the kart **coasts**. The simulation puts a
> number on it (`arret_urgence_plat`): from full speed on the flat, **~11 m** (10.7 m) on rolling
> resistance alone. On a slope it does not stop at all (`coupure_pente8/16`: 4.5 and 10.9 m/s
> eight seconds later). **The mushroom is the last resort; the brake is releasing A**,
> and the gamepad's button B is the emergency stop that actually brakes.
>
> If that is ever judged unacceptable, the documented fix is a **normally-closed relay
> shorting the motor phases**, coil on the switched rail: losing power re-closes the contacts
> and the windings short themselves. Not fitted.
>
> **A welded contact is no longer detected.** The old coil-side opto (GPIO22) saw the e-stop
> command even when the contact had welded shut, and the firmware disarmed and braked on that
> information. Nothing does now. The replacement is a **test, not a circuit**: press the
> mushroom at commissioning and verify with a multimeter that driver VB+ actually reaches 0 V.
> Welding happens on *closing* (inrush into the driver's bulk capacitors), and the relay always
> closes with the motors commanded off, so the exposure is small — but it is a real, accepted
> trade.
>
> **A reboot no longer powers the kart off** — and that is an improvement. The latch had to be
> re-asserted by software within ~700 ms of a reset, which it could not do, so a watchdog reset
> dropped the rail and the kart needed a fresh press on the priming button. The relay is now held by a physical
> switch: a reset just reboots, ~1 s of unpowered driver (coasting, motors safe), and the kart
> comes back **disarmed** with the boot recorded in the event log.
>
> **Parts actually used**
>
> | | part | coil | contacts |
> |---|---|---|---|
> | main relay | **YONGCHUAN YCL-12V-C**, automotive SPDT (85/86 coil, 30/87/87a) | 12 V, ~80 Ω, **150 mA** | **40 A** on 87 (NO), 30 A on 87a |
> | coil switches | ordinary **NC mushroom** + **toggle/key switch**, in series | they only break the 150 mA coil current | signal-gauge wire to the seatback |
> | coil diodes | **2× 1N4007** — one in SERIES (polarity gate), one ACROSS the coil (flyback) | 1 A / 1000 V, ~0.9 V drop on 150 mA | — |
>
> Feed everything from **87 (NO)**: it is the contact carrying the 40 A rating, and it also
> means an unpowered relay is an unpowered kart. The **1N4007** across the coil is required for
> the two mechanical switches (an inductive break arcs and erodes contacts). A **second**
> 1N4007 sits **in series** in the coil loop, and that one is the **reverse-polarity
> protection for the whole kart** — which is a property of the single-relay layout, not of a
> component: *everything* is behind the contact, so the only question a reversed battery has
> to answer is whether the relay closes. With a series diode gating the coil, it cannot: the
> coil sees nothing, the contact stays open, **no current reaches the system at all** and
> nothing is stressed. Put the battery back the right way and the kart starts — the protection
> is passive and repeatable, not single-use.
>
> A bare coil would not do this (a solenoid pulls in either way round), and the flyback diode
> alone would do it *badly*: reversed, it shorts the coil — the relay does stay open, but the
> 40 A fuse blows, the diode takes a surge far past its 1 A rating, and if it ever fails
> **open** the protection disappears without a sign. The series diode costs ~0.9 V on a coil
> that pulls in around 7–8 V, so the margin is wide. ⚠️ Fit it band-toward-the-relay: backwards,
> the relay simply never closes (a loud, harmless failure). ⚠️ And it does **not** cover a
> VB+/VB− swap made *downstream* of the contact — check that one by hand.
>
> **And the last GPIO input went with them.** The panel **arming button** (GPIO16) is gone
> too: arming already required a connected, calibrated gamepad whose own START/Options button
> the driver was holding, so the button on the kart duplicated a control already in hand — and
> a button on the vehicle is a button a bystander can press. The ESP32 now has **no input pin
> in use at all**: four motor pins and one LED line out, nothing else (the two I²C buses went
> with the wheel sensors on 2026-09-29).
>
> *(Dropped with this change: the opto relay module, the coil-sense optocoupler, the priming
> button, the arming button, the hidden FORCE ON toggle, the never-fitted hold capacitor, and
> the idle auto-power-off that depended on the latch.)*

---

## 5. Critical safety points (child)

> ⚠️ **There is no rollover protection.** Since 2026-09-29 nothing measures the speed, so
> nothing limits the turn — the owner's explicit decision, stated here so nobody assumes
> otherwise. The geometry (a_tip ≈ 0.53 g) and **`duty_cap`** are all there is. Simulation,
> 18T gearing, full-speed full turn, minimum tip margin in m/s² (< 0 = tips):
>
> | `duty_cap` | 2 children centred | 1 child off-centre (33 kg) | adult + child |
> |---|---:|---:|---:|
> | **1.0** (default) | +1.62 | **−0.24 TIPS** | **−0.07 TIPS** |
> | 0.9 | +2.29 | +0.44 | +0.59 |
> | 0.8 | +2.88 | +1.07 | +1.19 |
> | 0.7 | +3.42 | +1.61 | +1.73 |
> | 0.6 | +3.89 | +2.08 | +2.20 |
>
> The default stays **1.0** (the owner's call). Tested on the flat with 40 lb pellet bags, the
> kart could not be tipped — but the bags sit lower than a seated child, the kart is slower
> than before (18T), and the model has **never been calibrated against a real tip test**.
> Source: `testCapSweep` in [`firmware/test_host/sim_main.cpp`](firmware/test_host/sim_main.cpp).

- ⚠️ **Rollover**: never move seating or ballast toward the caster, keep the **wide track (83 cm)**, don't raise the seat (height is the other big term), and pick `duty_cap` knowing the table above. Start with a low `duty_cap`.
- ⚠️ **Mounting of the 2 rear drives**: motor mounts solidly bolted/reinforced; chains tensioned, lubricated and guards closed (never any slack — a slack chain climbs the sprocket and is thrown).
- ⚠️ **Front caster wheel**: axle and swivel well tightened (nylock / threadlocker); check it pivots freely with no binding, and that its 73 mm pad is solidly fixed — it carries the nose and the battery.
- ⚠️ **Driven-wheel axle secured**: nylock + **cotter pin/retaining washer**.
- ⚠️ **Chain/sprocket guard**: no fingers/laces/clothing caught.
- ⚠️ **Rounded corners**, sanding against splinters, bolt heads countersunk/capped on the child side.
- ⚠️ **Lap belt** anchored to the frame; **helmet mandatory**; **footrest**.
- ⚠️ **Central hardware emergency stop**: at the **top of the seatback, centered**, **easily reachable by both kids** (and by an adult behind); it **opens the main relay's coil** (~10-20 ms) and cuts **the entire kart, brain included**. ⚠️ **It does not brake — the kart coasts** (~11 m from full speed on the flat; on a slope it keeps accelerating). Teach it as "kill everything", not as "stop": the **brake** is letting go of **A**, and the gamepad's **button B** is the emergency stop that brakes. A **welded relay contact** is no longer detected in software — verify at commissioning that VB+ really dies when the mushroom is pressed. Check that the button is neither hidden nor blocked, and that the kids know how to use it.
- ⚠️ **Gamepad**: calibrated before each session; check that **releasing A** brakes, that **button B (software emergency stop)** brakes, and that a **disconnect** (gamepad off / out of range) triggers braking.
- ⚠️ **Inspection before each use**: motor mounts, chain tension + lubrication + sprocket tightness, **front caster (swivels free, pad solid)**, **central hardware e-stop** + gamepad e-stop, tech bay mounting (battery secured in the nose), electric brake test.
- ⚠️ **Flat ground, supervised**, away from traffic and slopes.
- ⚠️ **Plastic tires = little grip** → moderate speed, gentle turns, and **skid-steer scrub** in tight turns (see §3).

---

## 6. Adjustable seat

To adjust the **seatback ↔ front-of-seat** distance to the child's size:

| Method | Principle | Advantage |
|---|---|---|
| **A. Slotted sliding base** ✅ | The seat slides on 2 slotted rails, clamped with **wing nuts** | Continuous adjustment, no tools |
| **B. Row of holes** | Rebolt the seat in the right hole (every 3 cm) | Very solid, in steps |
| **C. Adjustable footrest** | Move the footrest instead of the seat | Seat fixed against the seatback |

👉 Recommended: **A** (sliding base + wing nuts) — as the child grows → slide the seat back. (No more pedal box to move: driving is on the gamepad.)

---

## 7. Mass estimate

> Assumptions: plywood ~600 kg/m³, 2×3 SPF stud ≈ 1.17 kg/m, drive wheel ~1.0 kg each, caster ~0.5 kg.

| Item | Mass |
|---|---:|
| Wood (6 mm plywood floor, 2×3 frame, mounts, bench, reinforcements) | ~18 kg |
| 2 rear drive wheels Ø25.4 cm + 1 front caster (10″) | ~2.5 kg |
| Fasteners / shoulder bolts | 1.6 kg |
| Propulsion (2 rear motors + 2 3D gearboxes + sprockets/#35 chains) | 3.8 kg |
| Electronics + battery (12 V motorcycle battery, driver, ESP32, relay, wiring) | 2.5 kg (⚠️ optimistic: a motorcycle battery alone is ~3–5 kg — re-weigh and update) |
| Brake/misc (seatbelt, guards, paint, gamepad) | 2.0 kg |
| **EMPTY TOTAL** | **≈ 32 kg** |
| + 2 kids (~33 kg each) | +66 kg |
| **LOADED TOTAL** | **≈ 98 kg** |

**Consequences:** wood dominates (~56 % empty) → the first lever for weight saving. Removing the steering parts (steering wheel, column, tie rod, steering knuckles) **saves weight** versus the 4-wheeler. **Where the mass sits matters more than how much of it there is:** the two kids (66 kg, two thirds of the loaded total) sit **6″ ahead of the driven axle**, which puts the CG 46 cm from it — it was 21 cm when they sat on it, and that difference is a quarter of the rollover margin. The battery (the one heavy item at the other end) is deliberately in the **nose over the caster** — it keeps that wheel planted while barely moving the CG. ⚠️ Anything heavy added later goes **at the rear**, never in the cabin's front half: the sim's `xcg_m` (distance CG→driven axle, **0.455 m**) is the number that would move, and the `duty_cap` sweep of §5 was computed at that value. Rolling resistance at ~100 kg ≈ **25 N** on the flat; the combined drive force of the 2 rear wheels is still enough at 61 % of the load → **OK on the flat**, realistic grade **~3–6 %**. Electric braking must be sized for ~100 kg.

---

## 8. Implementation plan (assembly & commissioning)

Order from simplest to riskiest. **Golden rule: test everything with the wheels in the air and at low speed before going on the ground.**

```mermaid
flowchart LR
    P1["1. Wooden frame"] --> P2["2. Rear wheels + front caster"] --> P3["3. Rear drives<br/>(2 motors + gearbox + #35 chains)"]
    P3 --> P5["4. Power<br/>(battery, main relay, driver)"]
    P5 --> P6["5. Control<br/>(ESP32, WS2812)"] --> P7["6. Firmware<br/>+ gamepad pairing/calibration"]
    P7 --> P8["7. Progressive tests"] --> P9["8. Final safety"]
```

**Phase 0 — Preparation.** Gather hardware (§4) and tools (drill, saw, wrenches, soldering iron, multimeter, 3D printer). Print the 2 gearboxes (1:13.33), the 18T and 32T sprockets + drilling template. Work with **batteries disconnected**.

**Phase 1 — Wooden frame.** **30″ × 46″ plywood deck** + the two **inboard 2×3 rails** running its full length, flush with its edges and **overhanging 150 mm at the nose** to carry the caster; crossmembers ~25–30 cm; **notches cut in the deck sides at the rear** so the drive wheels can be slid into place and then bear laterally on the rails; **tech bay in the nose** (~30 cm, over the caster); **continuous** 76 cm bench **6″ ahead of the driven axle**, leaving ~15 cm of deck behind it for the wheels and the drive stack (no divider) + **side guardrails** (1/2″ plywood, ~30 cm) + seatback. ✅ *Two people can sit without excessive flex; the guardrails hold a child who slides sideways well.* ⚠️ *Do not move the bench any further forward to "balance" the kart — the 6″ it has already moved cost a quarter of the rollover margin, and there is none left to spend.*

**Phase 2 — Rear wheels + front caster.** 2 Ø25.4 cm wheels at the rear on the **1/2″ threaded rod** (85 mm of rod per wheel: hub + spacers + lock nut), dropped **4″ below the rails on shims**, turning **free**; **pivoting 10″ caster** bolted under the nose overhang, its plate raised on a ~73 mm pad so both axles sit at the same height, pivot tight but free. ✅ *Rear track 83 cm, nothing rubs, both wheels touch the ground evenly; the caster orients itself when you push the frame.*

**Phase 3 — Rear drives (replaces the old "steering").** On **each rear wheel**: bolted 32T sprocket (large washers / backing plate) + 3D gearbox with its 18T output **ahead of and above the axle** (165 mm centre distance, 60 links, so chain slack hangs on the run instead of climbing the teeth) + motor on a reinforced mount + #35 chain cut to length + tension adjustment + guard. **No linkage**: steering is differential, so nothing to adjust on the steering-wheel/tie-rod side. ✅ *With no power: each rear wheel turns by hand, chain tensioned and lubricated.*

**Phase 4 — Power electronics ⚠️ (in the nose).** The **single 12 V pack in the NOSE, strapped in its retaining tray over the caster** (build the tray first: plywood plate + rims on the deck); **fuse 40 A AT the battery → main relay (contact 30→87) → +12V_SW rail → 10 AWG pair back to the rear motors**; the relay **coil** fed through the **main switch (dash)** and the **e-stop mushroom (NC, top of the seatback)** in series — thin wires, the contact is what breaks the 40 A — with **two 1N4007 on the coil**: one **in series** (band toward the relay — the polarity gate: a reversed battery energizes nothing and blows nothing) and one **across 85/86** (cathode to 85/+, flyback for the two switches). No latch, no priming button, no FORCE ON toggle, no capacitor. See [`doc/electronique.md`](doc/electronique.md) for the full wiring guide and [`doc/schematics/power_rails.png`](doc/schematics/power_rails.png) for the schematic; **mount the emergency-stop mushroom button at the top of the seatback, centered** (within reach of both kids and an adult behind); driver (⚠️ **VB+/VB- polarity**, and the coil diode does NOT protect this side) → 2 rear motors; **~10 AWG**, crimped lugs. ✅ *With a multimeter BEFORE connecting: polarity, ~12 V at the driver once the main switch is on, and **the e-stop kills everything — verify VB+ actually reads 0 V** (the only test that catches a welded contact). Then force a reset while powered: the kart must stay powered, reboot and come back disarmed. Finally, know the coast: with the kart rolling gently, press the mushroom and see how far it keeps going — it does not brake.*

**Phase 5 — Control electronics.** ESP32 + breakout; **buck → 5 V on the switched 12 V rail** (the ESP makes its own 3.3 V); motor driver PWM/DIR on GPIO 26/25 (left) and 33/32 (right); WS2812B (GPIO4). **No sensors, no buttons, no ADC, no divider, no sense line** — four motor pins and one LED line are the whole logic harness. ✅ *Common grounds, 3.3 V/5 V present.*

**Phase 6 — Firmware + settings.** `idf.py build flash monitor` (see [`firmware/README.md`](firmware/README.md)); later updates can go over Wi-Fi (System tab, or `POST /ota`). Wi-Fi **Kart-Config** → `http://kart.local` (or `http://192.168.4.1`). **Pair then calibrate the gamepad** (mandatory to drive), and check on the Gamepad tab which button lights as **A**. Nothing to calibrate on the wheels — there are no sensors. Set **`duty_cap`** (the only limit — read the [§5 table](#5-critical-safety-points-child) before choosing it), `turn_gain`, a child-friendly **mixing** (`mix_type` 1 = expo), `accel_pct_s` if the kart pulls away too abruptly, and `decel_pct_s` if the freewheel feels wrong. *(500 Hz loop, IPv6, System page with persistent event log: automatic.)*

**Phase 7 — Progressive tests (wheels in the air).** Arm (gamepad START held ~1 s), **hold A**, light forward → correct direction of **each wheel** (fix with `mot_inv_l` / `mot_inv_r`, or swap M1A/M1B); push the stick right → turns right (mirrored → `mot_swap_lr`, or rewire the channels); **release A → brake**; A held + stick released → the wheels slide down at `decel_pct_s`; test **pivot in place**, **disarm**, **gamepad emergency stop (B)** and **gamepad disconnect → braking**, **central hardware e-stop** (everything dies, including the page's connection — then power back on with the main switch: the kart must come back **disarmed**). Then on the ground: flat terrain, low `duty_cap`, 1 light child first, raise `duty_cap` **progressively**.

**Phase 8 — Final safety.** Seatbelt anchored, helmets, guards, rounded corners, footrest, secured axles, tightened caster, **nose tech bay secured**, **battery strapped in its nose tray**, **central emergency stop clear and tested** (everything dies, driver VB+ at 0 V). **Inspection before each use**. Use **under adult supervision**.

---

## Firmware

ESP-IDF 6.1 (C++) code in [`firmware/`](firmware/) — details in [`firmware/README.md`](firmware/README.md).

- **500 Hz control loop** (FreeRTOS 1000 Hz): **gamepad** read, **A-button gate** (A released → dynamic brake), pluggable mixing (linear / expo), **accel/decel ramps** (`accel_pct_s` / `decel_pct_s`), `duty_cap`, **independent PWM + DIR**. No sensor read of any kind — no encoders, no ADC, no power control: the pack is always 12 V and the kart is switched by hand. State machine, arming (gamepad START), gamepad heartbeat, **watchdog**. **Brake by default** from boot and if the gamepad disconnects.
- **FreeRTOS tasks** (priority / core / stack): see [`doc/firmware-tasks.md`](doc/firmware-tasks.md); constants in [`firmware/main/rtos.hpp`](firmware/main/rtos.hpp).
- **Bluetooth (gamepad) + Wi-Fi** in coexistence; **Wi-Fi AP + station**, **IPv6**, **mDNS** (`http://kart.local` on both interfaces — no IP to remember; Android excepted), **WebSocket** server: dashboard (scaled Chart.js graphs — forward command + PWM per wheel, worst control tick), live configuration, **Gamepad tab** (pairing, calibration, stick visualization), Wi-Fi, pinout, and a **System page** with the **persistent event log** (why did it disarm — survives reboots and power cuts). Settings that write flash are refused while armed.
- Build: `cd firmware && idf.py build flash monitor`.

---

## Known limitations and risks

Points to **address / validate before any real use**.

**Safety & access**
- **The central hardware emergency stop removes ALL power by opening the main relay** (mushroom in the relay's **coil loop** with the main switch, at the top of the seatback, within reach of both kids; ~10-20 ms). It stops the kart being powered, not the kart: with no gate drive there is no electric brake, so it **coasts** (~11 m from full speed on the flat, simulated). The firmware never sees it — it is off too — and the kart boots **disarmed** when power returns. Everything that actually brakes is software and needs power: releasing A, gamepad emergency stop (button B), disarm, watchdog, braking on gamepad disconnect.
- **Unauthenticated web — by choice**: only the AP password protects access (changing it is still recommended). **Gamepad calibration** is locked outside the disarmed/stopped state.
- **Gamepad dependency**: if the gamepad disconnects, the kart **brakes** (safety), but the driver loses directional control until reconnection → drive within Bluetooth range, gamepad charged.

**Firmware / control**
- **No wheel sensors**: nothing measures speed. So: no speed limit but `duty_cap`, **no rollover protection** (§5 — at the default 1.0 an off-centre load tips in simulation), no stall or thrown-chain detection (a stalled motor draws its current until the driver limits it), no speed on the page.
- **Pseudo-freewheel only**: the MDD20A cannot float its outputs in PWM/DIR mode, so "A held, stick centred" just targets 0 and lets the command slide there at `decel_pct_s` (100 %/s by default = 1 s from full) — nothing knows about slopes.
- **Dynamic brake only**: releasing A shorts the motors — force ∝ speed, so it slows the kart hard on the flat but only holds it to a creep downhill (~0.19 m/s on 8 %, ~0.50 m/s on 16 %, simulated; 16 % was a 3.6 m/s runaway at 1:17.07). Plugging (stick back with A held) **generates current spikes** (no regeneration) → relies on the driver's current limiting.
- **Model not calibrated**: the simulation's physical parameters (Ra, Iz, h_cg, x_cg, frictions) are estimates; the §5 rollover numbers are measurements of the model, not of the kart.

**Electrical / power**
- **Motor current 19.6 A ≈ 20 A/channel limit**: a prolonged wheel stall triggers the driver's limiting/heating. **No current measurement** in firmware.
- **Battery sag ~40 A** → risk of ESP32 brownout: good buck + bulk capacitor at its input. ⚠️ The ESP32 now shares the **one switched rail** with the motors (the old logic rail filtered that sag), so tap the buck close to the relay rather than at the driver's terminals, and keep ≥ 470 µF there.
- **Driver without reverse protection** (VB+/VB-): a reversed connection **destroys** it.
- **Single 12 V pack**: no paralleling, no diode-OR. It carries the full ~40 A — fuse, cable and relay sized accordingly.

**Mechanical**
- **Skid steer = scrub in tight turns**: the tires slide sideways when you turn hard (friction, wear, energy loss). Pivot in place = maximum scrub; avoid on abrasive surfaces. There is indeed a **command differential** between the 2 wheels, but **no mechanical differential** on the axle side.
- **Stability is geometry + `duty_cap`, nothing else** (a_tip ≈ 0.53 g since the bench and axle moved 6″ apart; no firmware protection since 2026-09-29). Keep nothing heavy toward the caster, don't raise the CG, and choose `duty_cap` from the §5 table.
- **Plastic under stress** (rim, 6 mm plywood floor) → risk of cracking; reinforce.
- **Hard PVC tires** → low grip; moderate speed.

---

## License

Project code and documentation under the **0BSD license** (see [`LICENSE`](LICENSE)): free to use,
copy, modify and redistribute, **for any purpose, with no conditions whatsoever**.

Exception: the **vendored third-party components** keep their own license —
[`firmware/components/`](firmware/components/README.md) (bluepad32: Apache-2.0; **btstack:
BlueKitchen license**, commercial use subject to their terms) and `firmware/main/assets/chart.min.js`
(Chart.js: MIT).

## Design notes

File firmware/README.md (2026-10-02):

# ESP32 Firmware — Differential-Drive Kart

**ESP-IDF 6.1** firmware (C++) driving **2 independent rear motors** (one per wheel):
**steering is done by the speed difference** between the two wheels (*differential /
skid steer*). The **front wheel is idle**: one free-pivoting 10″ caster, centred. Controlled by a
**Bluetooth gamepad** (START arms, **A held to drive**), **no sensor on the wheels** (stick →
PWM, bounded by `duty_cap`), safety features, a **WS2812B strip** and **Wi-Fi configuration**.

## Mechanical architecture (recap)

```
        FRONT
        🛞               ← 1 IDLE 10″ caster, centred (battery sits over it)
       /  \
      /    \             steering = L/R speed differential
     /      \            (pivots in place if forward ≈ 0)
     [bench]             ← 2 kids, 6″ AHEAD of the driven axle since 2026-08-10
   🛞 L      🛞 R       ← 2 DRIVE wheels, each its own motor + gearbox + 18T→32T chain
        REAR              (the CG sits 61 % of the way back from the caster; it
                           was 80 % when the bench sat ON the axle — that move
                           cost a quarter of the rollover margin)
```

- **"Arcade" mixing**: `left = forward + turn·gain`, `right = forward − turn·gain` (stick to
  the left → right wheel faster → the kart turns left). The stick→motor mapping is
  **pluggable** (`mix_type`, Drive feel group): **0 linear**, **1 expo** (gentle around
  center, full authority at the stops — recommended for a child).
- **Hold A to drive**: once armed, **A released = dynamic brake** whatever the stick says,
  **A held + stick = drive**, **A held + stick centred = pseudo-freewheel**. See
  [Driving](#driving-a-button-brake-and-pseudo-freewheel).
- ⚠️ **No rollover protection** (a_tip ≈ 0.53 g): nothing measures the speed, so nothing limits
  the turn — `duty_cap` is the only lever. At the default 1.0 the simulation tips the kart in a
  full-speed full turn with an off-centre load. See [Rollover](#rollover-no-protection-the-numbers).

## Build / flash

```bash
. ~/esp/esp-idf-6.1/export.sh
idf.py set-target esp32
idf.py build
idf.py -p /dev/ttyUSB0 flash monitor
```

### Over the air (OTA)

Once a board runs an OTA-capable firmware, no cable is needed (kart **disarmed**):

```bash
curl --data-binary @build/kart_firmware.bin http://kart.local/ota   # or the STA / 192.168.4.1 IP
```

— or the **System** tab of the page (file picker → *Upload & reboot*). The image goes to
the idle slot, is validated, and the board reboots into it. **Rollback** is on: if the new
image crashes before the end of `app_main`, the next reset returns to the previous one. The
upload is refused while armed and aborted if the kart gets armed mid-way (every chunk writes
flash, which freezes the control loop). ⚠️ No authentication: anyone on the kart's network
can flash it — same as the settings.

**Migrating a board from the old `factory` table (one time, by cable):** the partition
table, bootloader (rollback) and evlog location all change, so flash over serial and erase
the evlog's new area (it may hold stale bytes):

```bash
idf.py -p /dev/ttyUSB0 flash
python -m esptool -p /dev/ttyUSB0 erase-region 0x3E0000 0x10000
```

NVS (settings + gamepad pairing) does not move and survives; the old event log is lost.

> **Vendored components** (in [`components/`](components/), **committed** — a fresh clone
> builds without any manual step): `bluepad32`, `btstack`, `cmd_nvs`, `cmd_system`, **patched
> for IDF 6.1**. Provenance and patch details: [`components/README.md`](components/README.md).
>
> **Managed component**: `espressif/mdns` (declared in [`main/idf_component.yml`](main/idf_component.yml))
> is downloaded into `managed_components/` on the first build → **that build needs an internet
> connection**. mDNS was removed from ESP-IDF in v5; the registry is the only source.

### Bluetooth + Wi-Fi: radio configuration

The ESP32 shares a **single radio** between Wi-Fi and Bluetooth (TDM coexistence) and the app
grows significantly (~1.4 MB). Settings in [`sdkconfig.defaults`](sdkconfig.defaults):

- **Custom partition table** ([`partitions.csv`](partitions.csv)): **two OTA slots**
  `ota_0`/`ota_1` of 1.875 MB each (app ~1.5 MB, 4 MB flash), `otadata`, and a dedicated
  **64 kB `evlog` partition** at 0x3E0000 for the persistent event log. The NVS never moves
  (moving it would wipe the settings and the pairing).
- **BT enabled** (`BT_ENABLED`, **BTDM** mode = BLE + BR/EDR, *modem sleep* disabled) +
  **software coexistence** (`ESP_COEX_SW_COEXIST_ENABLE`).
- **Bluepad32**: **CUSTOM** platform (`BLUEPAD32_PLATFORM_CUSTOM`), audio disabled.
- **IRAM**: Wi-Fi + BT saturate the IRAM → `ESP_WIFI_IRAM_OPT` / `ESP_WIFI_RX_IRAM_OPT`
  disabled (Wi-Fi code moved to flash; negligible impact on control).

## Bluetooth gamepad (Bluepad32)

The backend ([`input_bp32.c`](main/input_bp32.c)) implements a **custom Bluepad32
platform** and runs the **BTstack** loop in a dedicated task (core 0). Gamepad frames
are passed to the firmware through C hooks (`inputbp_on_data` / `inputbp_on_conn`)
consumed by [`input.cpp`](main/input.cpp), which exposes the neutral interface
[`input.hpp`](main/input.hpp) (`input::get()` → `{x, y, connected, estop, start, drive}`).

- **Left stick**: `Y` = forward/reverse, `X` = turn (arcade mixing in the controller).
- **A button** = **hold to drive** (`drive`): Bluepad32's `BUTTON_A`, mask 0x01 — the button
  the page's Gamepad tab lights as "A", whatever is printed on the pad. Released = dynamic brake.
- **START/Options** = arming (held `arm_hold_ms`, stick centred).
- **Circle→square compensation**: the stick is mechanically bounded by a **circle**
  (`x²+y²≤1`) → at full diagonal each axis would cap at ~0.71. `input::get()` **radially
  stretches** the command (factor `|v|/max(|x|,|y|)`, =√2 on the diagonal) so that the
  **corners of the square become reachable**: full forward **and** full turn simultaneously.
- **B button** = **emergency stop** (immediate braking).
- **Haptic feedback** (`input::rumble`): a **soft** vibration on arming, a **strong** one on
  the e-stop, and a **strong (repeated)** one if you push the stick while the kart is **not
  armed** — only then: releasing A while armed is the normal way to brake and does not buzz. The request is posted by the control loop and
  played in the BT thread (`play_dual_rumble`).
- **Pairing / unpairing** driven from the web page (**Gamepad** tab).

### MANDATORY calibration

**The kart refuses to move until the gamepad is calibrated** (`input::get()`
returns zeroed axes if not calibrated → the controller stays braked). Calibration is
done **exclusively from the web page**, **for the gamepad only**:

1. **Center**: stick at rest → captures the neutral point.
2. **Extremes**: move the sticks fully → captures the amplitude per axis.

The scale (center + half-amplitude per axis) is **persisted in NVS** (namespace `pad`).
⚠️ **A (re)pairing ERASES the calibration** (new gamepad = new calibration).

### Safety: disconnect → braking

If the gamepad **disconnects** (out of range, dead battery, unpairing), `connected`
goes to `false`, **every axis and button reads neutral** (a stick frozen mid-deflection or
a latched e-stop bit must not outlive its gamepad), and the controller **immediately puts
both motors into braking mode**. Same if not armed, not calibrated, gamepad emergency stop,
or A released. On top of the BT-level disconnect there is a **heartbeat**: a link still
"connected" but silent for **750 ms** (Wi-Fi/BT coexistence can starve the HID stream for a
few hundred ms — 250 ms false-tripped mid-run) disarms and brakes without waiting for the
multi-second Bluetooth supervision timeout.

### Safety: anything wrong = braking (dead-man)

- **2 s task watchdog with PANIC** (`sdkconfig.defaults`): a frozen control loop → reboot
  (not just a warning); on restart the motors come back up in dynamic braking.
- **Motor pins: all low = braking** (duty 0 + DIR low short the bridge). The
  firmware arms **internal pull-downs** on PWM/DIR (high impedance → braking as long as
  the chip is running) and forces the braking state on the very first line of `app_main`.
- ⚠️ **Wiring required**: the internal pull-downs **do not survive a reset** (IO_MUX
  registers). During the bootloader (~700 ms), only **EXTERNAL pull-downs** (~10 kΩ) on
  the driver's PWM/DIR inputs guarantee braking — plan for them (or check that the
  driver module includes them). There is no power latch any more: the kart is held on by a
  physical main switch, so a reset simply reboots it (~1 s of unpowered driver = **coasting**)
  instead of powering it off. The **emergency stop** costs the same coasting, and for the same
  reason — it opens the main relay and drops the whole kart, ESP32 included (see
  [`../doc/electronique.md`](../doc/electronique.md)). Flat ground use, as the
  `coupure_pente*` and `arret_urgence_plat` simulation scenarios quantify (~11 m of coasting
  from full speed on the flat).

## No analog measurements at all

There is **no ADC on this kart** — no ADS1115, no internal ADC, no voltage divider. The pack
is always **12 V**, which is the motors' nominal voltage, so there is nothing to cap
automatically and nothing worth measuring. What went away with it: the low-voltage cutoff
(LVC), the 12/24 V detection at boot, the automatic `12 V / measured Vbat` PWM cap, the
battery gauge and chart on the page, and the `LVC` / `NO_VBAT` faults.

What remains as a power ceiling: the manual **`duty_cap`** setting. What remains as
deep-discharge protection: the battery's own. A flat pack is now something the driver
*feels* — the kart is simply slower, as the `batterie_usee` simulation scenario shows — not
something the kart reports.

### Physical joystick (reserved, not implemented)

The design provides for a **physical joystick** as an alternative to the gamepad. For now
**only Bluetooth is implemented**; the `input::` interface stays neutral so one could be added
behind it, but the two ADS1115 channels that used to be reserved for it went away with the
converter — a physical joystick would now need an ADC of its own.

### No wheel sensors

The **2× AS5600** encoders and their two I²C buses were removed on **2026-09-29**. Nothing
measures the wheels: no speed, no rpm, no encoder conditions (stuck / reversed / erratic /
absent / magnet — their bits and protobuf values are **retired, not reused**, so older
event-log records still decode to what they meant). Gone with them: the speed-limiter and braking PIDs
(`pid.hpp`), the rollover protection, the turn slew-rate, the speed-soft mixer (`mix_type` 2),
the reverse speed limit, and the settings `use_encoders`, `open_loop`, `mix_soft_hi`, `enc_per_wheel`,
`enc_inv_l/r`, `enc_rev_chk`, `speed_limit_ms`, `rev_speed_ms`, `brk_*`, `vlim_*`,
`turn_limit_en`, `turn_full_ms`, `turn_alat_vmax`, `turn_rate`, `dyn_brake_en`.

Free GPIOs: **13, 14, 16, 18, 19, 21, 22, 23, 27** and the input-only 34/35/36/39 — 13 and 22
were the power latch and the e-stop coil sense, 16 the arming button, 18/19 and 27/14 the two
I²C buses.

## Wireless configuration (SoftAP + WebSocket)

On startup, the ESP32 creates an access point:

- **SSID**: `Kart-Config`  ·  **password**: `kart12345`
- Open **http://kart.local** (mDNS) or **http://192.168.4.1**

The **Wi-Fi** tab lets you enter an SSID/password and **enable station mode**
(checkbox): the kart then connects to that network **while keeping the SoftAP**
(AP+STA mode). Applied **at restart**. Automatic reconnection with a **growing delay** (5 s after a drop,
then 10, 20, 40 s… up to 5 min; back to 5 s once connected) and **never while armed**: an
attempt scans every Wi-Fi channel on the radio the gamepad's Bluetooth shares.

### mDNS (`kart.local`)

The kart announces itself on the local network via **mDNS/Bonjour**
([`main/mdns_svc.cpp`](main/mdns_svc.cpp), managed component `espressif/mdns`), on **both
interfaces** (SoftAP *and* station): the same URL **http://kart.local** works whether you are
connected to `Kart-Config` or to the home network — no need to know the DHCP address, which
changes. The `_http._tcp` service is also published, so the kart appears on its own in the
network browsers (Bonjour, `avahi-browse`, Windows Explorer "Network"). The host name is
**also sent to the router's DHCP server** (`esp_netif_set_hostname`), so the kart shows up as
`kart` in the list of connected clients.

- Name defined in one place: `HOSTNAME` in [`main/mdns_svc.cpp`](main/mdns_svc.cpp); it is
  shown in the **System** tab and used for the DHCP host name.
- Supported out of the box on **Windows 10+, macOS/iOS and Linux** (Avahi).
  ⚠️ **Android**: Chrome does *not* resolve `.local` → use `http://192.168.4.1` from a phone.
- If two karts are on the same network, the library detects the collision and appends a
  number (`kart-2.local`).
- Cost: ~34 kB of flash and one low-priority task; a failure to start is **logged and
  ignored** — access by IP is never affected.

The page (7 tabs: **Dashboard / Graph / Configuration / Gamepad / Wi-Fi /
Documentation / System** — the pinout lives in the Documentation tab) communicates over **WebSocket** (`/ws`) using **binary Protocol Buffers** — a single
schema [`main/proto/kart.proto`](main/proto/kart.proto) (regenerate: `main/proto/generate.sh`),
encoded on the kart side by **nanopb** (vendored, callbacks → zero-copy/zero-heap, from the
static arena) and decoded browser-side by **protobuf.js** (`/pb.js` embedded, mirror JSON
descriptor in the page). Frames are ~3–10× smaller than the old JSON (status ≈ 150 B, full hist
≈ 0.9 kB). Whatever is **immutable at runtime is sent once when the page opens**:
config metadata ("get"), system info ("sysinfo"). After that: "vals" (values
only) after save/reload, "sysdyn" (uptime/heap/worst-tick) when the tab is shown,
charts ("hist") every 5 s, and the **persistent event log** ("evlog", System tab):
every arm, disarm (with the `Stop` cause of that very tick — the answer to "why did it
stop") and boot, journaled to the dedicated flash partition,
surviving reboots and power cuts. (The two power-off codes are retired with the power latch:
the firmware cannot cut its own supply any more, so a power loss now leaves no record —
the next Boot entry is what marks it.) Live state at **up to** 20 Hz — the page asks for the
next status only once the previous one has arrived, so a busy radio (a station retry scans
every channel) slows the refresh down instead of filling the socket with a backlog the page
then replays in one burst. Status badge, bars and I/O dots, plus **graduated Chart.js
charts** fed by an **in-RAM history**
on the ESP32 side. ⚠️ **While the kart is armed, everything that writes flash is
refused** — Save (config), Save & reboot (Wi-Fi), pairing/unpairing, calibration — a
flash write suspends the cache and would freeze the control loop mid-drive; the page
greys those buttons out with an amber "Kart armed" notice. The charts show the forward
command, the PWM of each wheel and the worst control tick — no speed or rpm, nothing measures
them. The **Gamepad** tab gathers: a **pairing button**, **gamepad
info** (name, battery, connection), an **unpairing button**, the **calibration mode**,
and a **real-time visualization**: a 2D pad showing **two points** — the **physical
position** of the left stick (blue, on the circle) and the **compensated command** circle→square
(orange, reaching the corners of the square), joined by a line — a 2nd pad for the **right stick**
(display only, not calibrated), the **directional cross (D-pad)**, the **button-state
dots**, the **ZL/ZR trigger bars**, and the **raw (hex) button mask** (to
identify the specific buttons of a gamepad).

## Software architecture

| File | Role |
|---|---|
| `pinout.hpp` | **Hardware pinout** (2 motors PWM/DIR, board LED, WS2812 — and the list of free GPIOs) |
| `control_types.hpp` | **PURE types shared host/target**: `KartConfig`, the `State`/`Stop`/`BrakeMode` enums, `hw::` constants, `ParamDesc` |
| `config_params.cpp` | **`PARAMS[]` table** (defaults/bounds/help) — PURE, also compiled by the simulation |
| `config.hpp` / `.cpp` | **NVS** persistence (write-if-changed; every save verb is **refused while armed**) + `KartStatus` telemetry + mutex |
| `hardware.hpp` / `.cpp` | Low-level hardware (`board::` — **2× PWM/DIR**, dynamic brake, LED). No inputs and no sensors: nothing is wired to a GPIO but the motors and the strip |
| `input.hpp` / `.cpp` | **Gamepad input** (neutral interface) + **mandatory calibration** (NVS); calibration/pairing refused while armed, collection forces a disarm |
| `input_bp32.c` | **Bluepad32/BTstack backend** (custom platform + BT loop task) |
| `controller_core.hpp` / `.cpp` | **Control CORE (`KartController`, PURE, host-compilable)**: A-button gate, mixing, accel ramp, pseudo-freewheel, arming, the `Stop` cause — output through an injected callback (`setCallbacks`), identical on ESP and in the simulator |
| `controller.hpp` / `.cpp` | `EspController`: wires the callback onto `board::`/`input::`, host advisor (rumble), event-log edges, loop-timing telemetry, 500 Hz task |
| `mixer.hpp` | **Pluggable stick→motor mixing** (abstract `Mixer`): linear / expo — `duty_cap` stays outside the mixers |
| `advisors.hpp` | **Host decision** from telemetry (PURE, shared with the sim): gamepad rumble |
| `evlog.hpp` / `.cpp` | **Persistent event log**: RAM ring pushed by the control task, drained to the `evlog` partition by the LED task **only while disarmed** |
| `ringbuffer.hpp` | Header-only ring buffer (history series) |
| `leds.hpp` / `.cpp` · `ws2812.*` | Status task (WS2812B strip, RMT driver) + event-log drain |
| `mdns_svc.hpp` / `.cpp` | **mDNS** responder (`kart.local`, `_http._tcp`) |
| `webserver.hpp` / `.cpp` | SoftAP + **HTTP/WebSocket** server (protobuf verbs, armed-lockout guards, event-log replies) |
| `assets/` | `index.html` + `style.css` + `chart.min.js` + `pb.min.js` — **gzipped at build** and served with `Content-Encoding: gzip` |
| `main.cpp` | `app_main`: subsystem init + task startup |

### Physics simulation + 3D visualizer

The SAME logic (`controller_core.cpp`) drives a **physics model of the vehicle**
(`test_host/sim/vehicle.hpp`: differential dynamics, DC motors with back-EMF, the 1:23.70
drivetrain, battery with internal resistance, slope, **rollover criterion for 3 OR 4 wheels**
(`VehicleParams::wheels` — the abandoned tricycle is kept so the scenarios can still show why)
through **20 extreme and realistic scenarios** (list: `test_host/sim/scenarios.hpp`): full turn
at full speed (no protection — off-centre loads tip at `duty_cap` 1.0), the old layout, pivot,
slalom, erratic driving, plugging, reverse, the A button (`sans_bouton_A`, `relache_A`,
`roue_libre_A`), gamepad loss (heartbeat), e-stop coasting, worn battery, descents on the
dynamic brake, power cut on a slope… plus a **`duty_cap` sweep** (full-speed full turn × three
loads) and the core output tests. The rollover runs are **measurements pinned as asserts**: they
document the danger and keep the README's numbers honest (a change that moves them fails the
build) — they do not block the tipping default.

- **Automated tests**: `test_host/run_tests.sh` (run by CI). CSV trace:
  `KART_SIM_TRACE=trace.csv ./sim`.
- **Real-time 3D visualizer**: `python3 tools/sim_viewer.py` → http://localhost:8650/ —
  same scenarios, 3D view (chase camera, trail, roll proportional to a_lat,
  ROLLOVER alert), margin gauge and live status badges.
- The ESTIMATED physical parameters (Ra, Iz, h_cg, x_cg, frictions) are grouped and
  commented in `VehicleParams` — to be recalibrated with real measurements.

Tasks: **`control`** (core 1, 500 Hz, 2 s watchdog with PANIC), **`leds`** (core 0, ~20 Hz,
also drains the event log) and the **BTstack loop** (core 0). Sharing of `g_cfg` and
`g_status` (mutexes); gamepad state passes through the atomics in `input.cpp`. FreeRTOS runs
at **1000 Hz**.
Priorities / cores / stacks: [`main/rtos.hpp`](main/rtos.hpp) · [`../doc/firmware-tasks.md`](../doc/firmware-tasks.md).

## Control loop (500 Hz)

1. Reads the gamepad (`input::get()` → `x`, `y`, `connected`, `estop`, `start`, `drive`).
   That is the only input: **no sensor is read** — no I²C, no ADC.
2. **Safety gate**: disconnected, silent for 750 ms (heartbeat), B pressed or not calibrated →
   disarm + dynamic brake. START held `arm_hold_ms` with the stick centred arms.
3. Armed: **A released** → dynamic brake, whatever the stick says. **A held + stick** (outside
   `thr_deadzone`) → the selected **mixer** (`mix_type`: 0 linear / 1 expo) maps
   `(forward y, turn x)` → left / right wheel commands. **A held + stick centred** →
   pseudo-freewheel: the last command runs down toward 0 (see [Driving](#driving-a-button-brake-and-pseudo-freewheel)).
4. Output **capped** by the manual `duty_cap` — the single ceiling on everything — then
   `mot_inv_l` / `mot_inv_r` / `mot_swap_lr` applied, and **independent PWM + DIR** to the
   driver's 2 channels.

`can_drive` requires: gamepad **connected**, **calibrated**, **armed**, no emergency stop —
and the kart only moves while **A is held**. Otherwise → **braking of both wheels** (the
**default** state, from boot). The web page **names the reason** it will not drive
(disconnected, silent, gamepad e-stop, not calibrated) — one at a time, highest priority first.

Safety features: **arming** by a ~1 s press on the gamepad's **START/Options button** — the
only arming input there is, now that the board has no GPIO inputs left (centered stick +
connected, calibrated gamepad required; starts **disarmed**),
**anything in the way forces disarming** (you must rearm once it is resolved), **hold-to-drive A**
(released = brake), **auto disarm** after `disarm_s` without driving (A held + stick),
**gamepad emergency stop** (B button → immediate braking), **gamepad heartbeat 750 ms**,
**2 s watchdog with PANIC**, and the **persistent event log** so a disarm that nobody saw
still has its cause on record.

The **hardware emergency stop is not in that list, by construction**: the mushroom sits in
the main relay's coil loop and cuts the ESP32 along with the motors, so the firmware never
sees it, reports nothing and brakes nothing — the kart coasts (~11 m from full speed on the
flat, measured in simulation). Power returns on the main switch and the kart boots
**disarmed**, which is what the old "re-arm after an e-stop" rule enforced in software.

The web page's **Dashboard** tab names **why the kart will not drive** (`enum class Stop` in
`control_types.hpp` — one cause, highest priority first), with explanation and remedy, and the
tab turns red while there is one. For a cause already GONE by the time anyone looks, the
**System** tab's event log holds the history.

There is no **fault** layer any more (removed 2026-09-30): no mask, no `Fault` enum, no
`State::Fault`, no red "fault" state on the page. Every sensor that could report a breakage
left one after the other — the battery ADC, the relay-coil sense, the encoders — and what
remained were four ordinary gamepad conditions, none of which is a failure. They still disarm
and brake; they are simply named for what they are.

### Driving: A button, brake and pseudo-freewheel

Once armed, the A button decides the output mode (`BrakeMode` in `control_types.hpp`, shown
permanently on the page):

| Input | Mode | What the driver's outputs do |
|---|---|---|
| **A released** (any stick) | `DYNAMIC` | PWM 0 + DIR low on both channels → both motor terminals grounded: **short-circuit brake** |
| **A held + stick** | `NONE` | the mixed stick, capped by `duty_cap`, rising no faster than `accel_pct_s` and falling no faster than `decel_pct_s` |
| **A held + stick centred** | `COAST` | the target becomes 0 and the command **slides there at `decel_pct_s`** (100 %/s by default = one second from full). Once it arrives, the mode becomes `DYNAMIC` — at 0 the windings are grounded, so calling it a coast would be a lie |

Disarmed, not calibrated, gamepad lost or silent, B pressed → `DYNAMIC` too; that is the
default state from boot.

**Why "pseudo".** The Cytron MDD20A has **no coast / high-impedance state** in PWM/DIR mode:
its truth table ([manual](../doc/datasheet/motor-driver-20A-manual.pdf), Table 3, printed
p. 3) has PWM low → MxA and MxB both low → **Brake**, whatever DIR. So a real freewheel is not
available, and the firmware imitates one: a centred stick targets 0 and the command **slides**
there rather than dropping, so the motor neither pushes nor brakes much on the way.

That slide has no setting of its own — it is simply `decel_pct_s`, the falling half of the
ramp pair. It used to be a duration (`coast_s`, then `coast_ms`), until the obvious was pointed
out on the bench: a run-down *is* a deceleration rate, and having one slope in %/s and the other
in milliseconds was the same idea told twice. At the 100 %/s default (one second from full
PWM) ~1.88 m/s is left half a second after centring the stick, against ~1.57 m/s half a second
after releasing A (`relache_A`) — the numbers the old 1000 ms produced, unchanged. The earlier
10 s, the pace of a true coast measured against `arret_urgence_plat`, was far longer than any
driver expects between centring the stick and stopping. Once at 0 it is electrically the brake
and the mode says `DYNAMIC`. Tuned for the flat: nothing measures a slope. ⚠️ The old
`dyn_brake_en = 0` "freewheel" option **never freewheeled on this driver** — duty 0 is the same
PWM-low state, i.e. it braked.

### Rollover: no protection, the numbers

A tricycle tips about the line from its SINGLE wheel to one of the paired wheels, so the
usable half-track is `(distance CG→single wheel)/wheelbase`. This kart puts the bench 6″
ahead of the PAIRED (driven) axle, which keeps 61 % of it — 254 mm of a 416 mm half-track,
a_tip 5.16 m/s² (0.53 g). **Nothing in the firmware limits the turn** since 2026-09-29 — the
owner's decision, taken when the wheel sensors went (a speed-dependent turn limit needs a
measured speed). `duty_cap` is the only lever. Full-speed full turn, 18T gearing, minimum tip
margin in m/s² (`testCapSweep` in [`test_host/sim_main.cpp`](test_host/sim_main.cpp)):

| `duty_cap` | 2 children centred | 1 child off-centre (33 kg) | adult + child |
|---|---:|---:|---:|
| **1.0** (default) | +1.62 | **−0.24 TIPS** | **−0.07 TIPS** |
| 0.9 | +2.29 | +0.44 | +0.59 |
| 0.8 | +2.88 | +1.07 | +1.19 |
| 0.7 | +3.42 | +1.61 | +1.73 |
| 0.6 | +3.89 | +2.08 | +2.20 |

The default stays 1.0 (the owner's call). A flat-ground test with 40 lb pellet bags could not
tip it — the bags sit lower than a seated child, and the model has never been calibrated
against a real tip test. The sweep asserts that 0.9 and below keep every load upright with
more than +0.3 m/s² to spare; it does not stop anyone from driving at 1.0. **Reverse** is as fast as forward
(`marche_arriere`: −2.56 m/s) — there is no separate reverse limit any more.

Web parameters: **`duty_cap`**, **`turn_gain`** (and the Drive feel group: **`mix_type`**,
**`mix_expo_fwd`**, **`mix_expo_turn`**, **`accel_pct_s`**, **`decel_pct_s`**).

### The two ramps (`accel_pct_s`, `decel_pct_s`)

The stick sets a **target**; the ramps bound how fast the command may travel to it, both in
**% of full duty per second** (`ctl::ramp`, control_math.hpp):

| | Default | What it is for |
|---|---|---|
| `accel_pct_s` — **rise**, away from 0 | 200 %/s (half a second to full power) | the **motor drivers**: a stick slammed open is a step from 0 to full duty, and a brushed motor answers a step like that with its stall current |
| `decel_pct_s` — **fall**, back toward 0 | 100 %/s (one second from full power) | the **pseudo-freewheel**, and smoothing a stick pulled back |

0 disables either side — the command then jumps straight to the target that way. A **reversal**
is the two in sequence: down to 0 at the fall rate, then up the other way at the rise rate (a
tick that finishes the fall spends what is left of itself building the other way, so plugging
never stalls at zero).

Both rates are in **real duty**, hence the division by `duty_cap` in the core: lowering the cap
makes the kart slower without secretly retuning the ramps, so "one second from full power"
stays one second.

⚠️ Neither ramp can delay the **brake**. Releasing A, disarming, B, a lost or silent gamepad —
every one of those grounds the windings on the tick it happens, whatever the ramps are doing.
The ramps only shape a command the driver is still asking for.

## ⚠️ To adjust before first startup

- **Motor directions**: wheels in the air, **A held**, forward stick — both wheels must turn
  forward; fix with `mot_inv_l` / `mot_inv_r` (or swap the motor leads). Then a turn: stick
  left must speed up the RIGHT wheel — if the steering is mirrored, the motors are on the
  wrong driver channels: rewire them or set `mot_swap_lr`. Then release A: both wheels brake.
- **Battery**: nothing to set up — always 12 V, never measured. Charge it on a schedule;
  the kart will not warn you.
- **Gamepad**: pair (Gamepad tab) then **calibrate** — mandatory to drive. Check which button
  the tab lights as **A**.
- **Web settings**: `duty_cap` (the only limit — read the [rollover table](#rollover-no-protection-the-numbers)
  first), `turn_gain`, `mix_type` (1 for a child driver), `accel_pct_s`, `decel_pct_s`. Start **wheels up**, low
  `duty_cap`.

> Check the **direction of each wheel** (swap the motor wires if needed) and the **direction of the
> differential** (pushing the stick to the right must turn right) **before touching the ground**.

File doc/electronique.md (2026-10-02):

# Electronics — design, BOM and wiring guide

The electronics chapter of the kart, in the same spirit as [`reducteur.md`](reducteur.md) for
the drivetrain: every choice with its **why**, the verified parts list, and the
terminal-by-terminal wiring guide. The firmware side of every signal named here is described
in [`../firmware/README.md`](../firmware/README.md).

**Design inputs (fixed):** single **12 V** motorcycle battery — always 12 V, never measured ·
**5 V rail ≥ 2 A** (it powers everything: ESP32, WS2812 strip) · **ONE main relay
carries the whole kart**, its coil in series with the **main switch** and the **e-stop
mushroom** · **two 1N4007 on that coil**: one **in series** (the coil energizes in ONE
polarity only — the relay becomes a polarity gate in front of the whole vehicle) and one
**across** it (flyback for the two switches) · ESP32 confirmed · **no sensors** (the two AS5600
wheel encoders, their I²C buses and pull-ups went on 2026-09-29) · **no ADC, no voltage
divider, no power latch, no buttons**: the ESP32 has no GPIO input left at all.

Single-relay power

> Regenerate: `. .venv-schem/bin/activate && python doc/schematics/power_rails.py`
> (environment: [`schematics/requirements.txt`](schematics/requirements.txt)). The whole-kart
> schematic is [`schematics/full_schematic.png`](schematics/full_schematic.png).

## 1. Architecture — one relay, one rail

| | |
|---|---|
| **Coil circuit** (~150 mA, thin wire) | fused battery + → **MAIN SWITCH** → **1N4007 in SERIES** → **E-STOP (NC mushroom)** → pin **85**; **86** → ground. Plus a second **1N4007 across 85/86**, cathode on 85. |
| **Contact** (30 → 87, the 40 A path) | feeds **+12V_SW**: the buck (→ 5 V: ESP32, WS2812), the motor driver's **VB+** *and* its logic board. |
| **Dies when** | the main switch is turned off, the mushroom is pressed, the fuse blows, or the battery is disconnected. There is no fourth case — **the firmware has no say in it at all**. |

This replaces the old two-rail design (logic relay module held by `POWER_HOLD` + separate
40 A motor relay + coil-sense opto on GPIO22). What was bought for that complexity, and what
it costs to drop it, is spelled out below — the trade is real, and it is deliberate.

### What the e-stop now does — and what it does not

Pressing the mushroom opens the coil loop, the contact opens in ~10–20 ms, and **the whole
kart goes dark: motors and brain together**. Consequences, stated plainly:

- **Nothing brakes.** The driver's MOSFETs open, the motors freewheel. Simulated and asserted
  in [`scenarios.hpp`](../firmware/test_host/sim/scenarios.hpp) (`arret_urgence_plat`): hit at
  full speed on the flat, the kart **coasts about 11 m** (10.7 m) on rolling resistance alone
  before stopping. On a slope it does not stop at all — `coupure_pente8` reaches 4.5 m/s eight
  seconds after the cut, `coupure_pente16` 10.9 m/s. **The e-stop is the last resort, not the
  brake.** The brake is releasing the gamepad's **A** button (dynamic braking — it needs power).
- **Nothing is reported.** No `MOTOR POWER` fault, no event-log record, no page notification —
  the firmware that would write them is off. The web page simply loses its connection.
- **Nothing is remembered.** Power returns on the main switch, the ESP32 boots, and the kart
  comes up **disarmed**, as it does after any boot: a deliberate hold on the gamepad's START
  is required. The
  old "re-arm after the e-stop" rule is now automatic rather than enforced in software.
- **A welded contact is invisible.** The old coil sense caught that case in software; nothing
  does now. It is on the watch list (see the decision log), and the counter-measure is the
  commissioning test below: press the mushroom, verify with a multimeter that VB+ actually dies.

> If coasting after a power cut is ever judged unacceptable on a slope, the hardware fix is a
> **normally-closed relay shorting the motor phases** when power goes away — dynamic braking
> that survives the cut. Not fitted; documented because the simulation quantifies exactly what
> it would buy.

### Start / stop

- **Start**: turn the **main switch** on (key or toggle, on the dash, e-stop released). The
  relay closes, the buck comes up, the ESP32 boots in ~700 ms and starts **disarmed**.
- **Arm**: hold the gamepad's **START/Options** button for 1 s with the stick centered. There
  is **no button on the kart** any more — the arming button on GPIO16 is gone with the rest of
  the GPIO inputs. Arming already demanded a connected, calibrated gamepad, so the button only
  ever duplicated a control the driver was holding anyway; removing it also means nothing on
  the vehicle can be pressed by a bystander.
- **Stop**: main switch off, or the mushroom. Both are hardware, both are absolute.
- **Reboot is no longer a power-down.** With the old latch, a watchdog reset dropped the rail
  and turned the kart off; now the relay is held by a physical switch, so the ESP32 simply
  reboots and comes back disarmed. That is strictly better: a reset while driving costs ~1 s
  of dead time (motors unpowered, gearbox not back-drivable) instead of a total shutdown.
- **No hidden FORCE ON switch**, no priming button, no hold capacitor: the main switch *is*
  the bench switch, and USB power alone runs the ESP32 for flashing with the relay open.

### The relay is a polarity gate

This is the real reverse-polarity protection, and it is a consequence of the single-relay
layout rather than of any one component: **nothing on this kart is powered until the contact
closes, and the contact only closes if the coil is energized.** Make the coil energize in one
polarity only and the whole vehicle is gated — the motor driver (no reverse protection of its
own, destroyed instantly by reversed VB+), the buck, the ESP32, the LED strip, all of it sits
behind that one contact.

A relay coil does **not** do that by itself: it is a solenoid, it pulls in whichever way the
current flows. So the coil carries **two 1N4007, with two different jobs**:

| Diode | Where | What it does |
|---|---|---|
| **Series** | in the coil loop (between the main switch and the mushroom), **band/cathode toward pin 85** | **The gate.** Reversed battery ⇒ it blocks ⇒ the coil sees nothing ⇒ the contact stays open ⇒ **no current reaches the system, and nothing is stressed**. Re-wire the right way round and the kart starts. Costs ~0.9 V on the coil. |
| **Flyback** | across the coil, 85/86, **cathode on 85 (+)** | **The arc killer.** When either switch opens the coil, the collapsing field would otherwise break a few hundred volts across the contact that just opened, eroding the mushroom and the main switch. Does nothing in normal operation. |

**Why the series diode, when the flyback one alone already keeps the relay open.** It does
keep it open — reversed, the flyback diode is forward-biased across the coil and shorts it, so
the coil cannot pull in either. But it does that by *conducting the fault*: the 40 A fuse
blows, the diode takes a surge far beyond its 1 A rating, and the protection is **single-use**
— worse, a 1N4007 that fails **open** removes it silently, and the next reversed connection
energizes the coil normally. The series diode makes the same protection **passive and
repeatable**: the reversed connection simply does nothing at all.

**The voltage it costs is free.** The coil draws ~150 mA at 12 V (~80 Ω); the diode drops
~0.9 V at that current, so the coil sees ~11 V on a fresh pack and ~10.4 V with the battery
sagged to 11.3 V. A 12 V automotive relay pulls in around 7–8 V and holds well below that, so
the margin stays wide. Use a plain 1N4007 (1 A / 1000 V) — the same part as the flyback.

⚠️ **Fit the series diode the right way round**: band toward the relay (pin 85). Backwards, the
relay never closes at all — which is a loud, immediate, harmless failure, and exactly the
failure mode you want from a protection device.

⚠️ **What it still does not cover**: a **VB+/VB− swap made downstream of the contact**, at the
driver's own terminals. That wiring is on the far side of the gate, so only the polarity check
at step 5 of the wiring guide stands between that mistake and a dead driver.

### 5 V rail — the ≥ 2 A budget

| Consumer | Worst case | Note |
|---|---:|---|
| WS2812 ×10 | ~0.60 A | 60 mA/LED full white; status colors at brightness 64 draw far less |
| ESP32-WROOM (via its 3.3 V LDO) | ~0.70 A | Wi-Fi TX bursts; sustained is ~0.24 A |
| Motor-driver logic inputs | ~0.02 A | PWM/DIR are 3.3 V signals; board logic is on +12V_SW |
| Margin / future (buzzer, lights) | ~0.6 A | |
| **Total** | **≈ 1.9 A** | **buck must sustain 2 A continuous at 11–14.8 V in** |

The on-hand buck is a 20 V-rated module reused at 12 V input — **verify its continuous
rating** (label/heatsink): if it is not clearly ≥ 2 A (3 A class recommended), replace it.
At the WS2812 strip head: the classic **470–1000 µF electrolytic across 5 V/GND** and
**~330 Ω in series with DIN** (first-LED protection), data wire kept short.

### The battery is not measured

One 12 V motorcycle pack, which is also the motors' nominal voltage. Nothing scales it down,
nothing reads it: **no ADS1115, no 100 k/15 k divider, no low-voltage cutoff, no 12/24 V
detection, no automatic PWM cap**. The only power ceiling left in the firmware is the manual
`duty_cap` setting on the config page.

What this gives up, honestly: the kart will no longer warn you about a flat pack, refuse to
drive on one, or cut its own power after 30 s of low voltage. A worn battery now shows up as a
kart that simply **feels slower** — simulated in `batterie_usee` (11.2 V, 0.12 Ω: it drives, at
reduced speed, with no fault of any kind). Deep-discharge protection is the pack's own
business. Check the charge on the battery's indicator, off the kart, and charge it on a
schedule rather than on a warning.

### Protections

| Risk | Measure |
|---|---|
| Short / overload | **40 A blade fuse** in a holder, as close to the battery + as possible — everything downstream is protected, relay included |
| Reversed battery connection | **1N4007 in SERIES in the coil loop** (see above): the coil cannot energize, so the relay never closes and nothing downstream is powered — no current, no damage, no part to replace. Plus polarized connectors + color discipline (red/+, black/−) |
| Coil kickback eroding the switches | that same **1N4007 across 85/86** |
| ESP32 brownout during motor surges | bulk electrolytic (≥ 470 µF) at the buck input; keep the buck's input tap off the motor cables' IR drop |
| No braking after a power cut | **behavioral**: the e-stop is a last resort; the brake is the stick. Hardware option documented above (NC relay across the phases) |

## 2. BOM (electronics)

| # | Part | Spec / rating | Qty | Role |
|--:|---|---|--:|---|
| 1 | Motorcycle battery | 12 V lead-acid, ≥ 40 A peak | 1 | single pack, **in the NOSE** — strapped in a retaining tray above the front caster (counterweight) |
| 2 | Blade fuse + holder | **40 A** | 1 | master protection at battery + |
| 3 | Automotive relay | 12 V coil, **40 A** on 87 (NO), SPDT | 1 | **the** main relay: whole kart |
| 4 | Diode 1N4007 | 1 A / 1000 V | **2** | one **in series** in the coil loop (polarity gate) + one **across** the coil (flyback) |
| 5 | E-stop mushroom | NC, latching (coil current only: ≥ 1 A) | 1 | in the coil loop, top of seatback — thin wires |
| 6 | Main switch | toggle or key, ≥ 1 A, panel mount | 1 | in the coil loop, on the dash — the on/off of the kart |
| 7 | Buck converter | 12 V in → **5 V ≥ 2 A cont.** (3 A class) | 1 | 5 V rail |
| 8 | ESP32-WROOM board | dual-core, 4 MB | 1 | controller |
| 9 | Motor driver | Cytron MDD20A: dual channel, 20 A/ch, 6–30 V, PWM+DIR | 1 | both rear (driven) motors |
| 10 | Resistor ~330 Ω | ¼ W | 1 | WS2812 DIN series |
| 11 | Capacitors: ≥ 470 µF (buck in), 470–1000 µF (LED strip) | 16 V+ | 2 | bulk + decoupling |
| 12 | WS2812B strip | ~10 LEDs, 5 V | 1 | status display (GPIO4) |
| 13 | Enclosure ~150×100×70, clear lid | ≈ IP65 + cable glands | 1 | ESP32 + perfboard |
| 14 | Wire: 10 AWG (power), 18–22 AWG (signal) + lugs/ferrules | — | — | power vs signal, crimped |

*Dropped from the previous build: the opto relay module, the second relay, the coil-sense
optocoupler, the ADS1115, the 100 k/15 k divider pair, the 100 nF at A0, the hidden FORCE ON
toggle, the priming/arming momentary button — and with it the last GPIO input on the board.
Dropped on 2026-09-29: the two AS5600 breakouts, their diametric magnets and the four 4.7 k
I²C pull-ups — nothing on the kart measures the wheels any more.*

## 3. Wiring guide — terminal by terminal

Work with the battery disconnected; connect it last.

1. **Battery + → fuse holder (40 A) AT the battery**, in the **nose tray above the front
   caster** — the battery, the relay, the buck and the driver all live in that bay, so these
   runs are short. The long pair is the **motor wiring**: 10 AWG **nose→rear** along a frame
   rail to the two driven wheels (≈ 1.1 m each way: ~7 mΩ round trip, ~0.3 V at 40 A — fine).
   Battery − → common ground bus (10 AWG). Keep signal looms on the other rail, away from
   that run.
2. **Fused + → relay pin 30** (10 AWG).
3. **Coil loop** (18–22 AWG): fused + → **main switch** (dash) → **1N4007 in series, band
   (cathode) toward the relay** → **e-stop mushroom (NC, top of seatback)** → **85**; **86** →
   ground bus. Then the second **1N4007 across 85/86, cathode (ring) on 85**. The order of the
   two switches matters only for reach — either one cuts the same loop — but the **series
   diode's direction does matter**: backwards, the relay never closes. Solder it inside the
   enclosure with short leads, not in the middle of the loom.
4. **Relay pin 87 → +12V_SW bus** (10 AWG, short run inside the nose). **87a stays spare.**
5. **+12V_SW → driver VB+** (10 AWG) and **→ driver logic supply** (18 AWG). Driver VB− →
   ground bus (10 AWG). The driver's two motor outputs are what run nose→rear (step 1). ⚠️ **Triple-check VB+/VB− polarity before the battery goes in — the
   driver has no reverse protection, and it sits on the far side of the relay contact, so the
   coil diode cannot save it from a swap made here.**
6. **Buck**: IN ← +12V_SW (+ ≥ 470 µF bulk at its input), OUT 5 V → ESP32 5V/VIN, WS2812
   strip (with its 470–1000 µF at the strip head), ground to the bus.
7. **Motor driver signals**: PWM_L/DIR_L ← GPIO26/25, PWM_R/DIR_R ← GPIO33/32, driver
   signal ground to the ESP32 ground.
8. **WS2812**: DIN ← GPIO4 through ~330 Ω; 5 V and GND from the buck.
9. Separate runs for power (10 AWG) and signal looms; keep the signal wires away from the
   motor cables. **Nothing else connects to the ESP32**: no sensors, no buttons, no analog
   inputs, no sense lines — the four motor-control pins and the LED data line are the whole
   harness on the logic side. Free: GPIO 13, 14, 16, 18, 19, 21, 22, 23, 27 and the input-only
   34/35/36/39.

### Power-up checklist (multimeter, battery just connected)

1. No continuity between +12V_SW and ground, **with the main switch off** (before anything).
2. **Main switch on**: the relay clicks, +12V_SW present, buck outputs 5.0 V, ESP32 boots
   (status LED, then the Wi-Fi access point). The page shows the kart **disarmed**.
   ⚠️ **The relay does not click?** Check the battery polarity and the series diode's direction
   *before* anything else — those are the two things that stop the coil energizing, and both
   are harmless as long as you do not "fix" them by bypassing the diode.
3. **Press the e-stop**: the relay drops, **everything** goes dark — verify with the
   multimeter that **driver VB+ is actually at 0 V** (this is the only test that catches a
   welded contact; nothing in software can). The web page loses its connection, which is the
   expected symptom, not a fault.
4. **Release the e-stop**: the kart powers back up and comes back **disarmed** — it must NOT
   resume driving on its own. Re-arm with the gamepad's START.
5. **Coast test (do it once, know the number)**: on a flat open surface, at moderate speed,
   press the mushroom. The kart **keeps rolling** — measure roughly how far. The simulation
   says ~11 m from full speed; feel it at half speed so the number means something when it
   matters. **Never test this on a slope.**
6. **Reboot test**: trigger a reset while powered (flash, or watchdog). The kart must stay
   powered, reboot in ~1 s and come back **disarmed** (this is a change from the old latch,
   where a reset powered the kart off).

## 4. Decision log

### 2026-09-29 — the wheel sensors go

| Decision | Chosen | Why |
|---|---|---|
| AS5600 wheel encoders (2× I²C) | **removed** | the owner's simplification: stick → PWM, bounded by `duty_cap`. Two breakouts, two magnets, four pull-ups and two buses (GPIO 18/19, 27/14 — now free) out of the harness, and no sensor fault can stop the kart any more |
| Speed limit, braking PID, rollover protection | **removed with them** | all three needed a measured speed. Cost, stated: nothing limits the turn — in simulation a full-speed full turn at `duty_cap` 1.0 tips with an off-centre load (numbers: [README §5](../README.md#5-critical-safety-points-child)) |
| Braking | **dynamic brake on A released** | the MDD20A grounds both outputs whenever PWM is low (manual, Table 3) — that is the brake, and it is also why a real freewheel is not available: "A held, stick centred" only imitates one |

### 2026-09-20 review — the simplification

| Decision | Chosen | Why |
|---|---|---|
| Power architecture | **ONE relay for the whole kart** | the two-rail split existed so the brain could survive the e-stop and report it; that reporting bought a fault message, not a stop — and it cost a second relay, an opto, a sense pin and a software path. One relay, one rail, one failure mode |
| E-stop position | **in the coil loop, with the main switch** | the mushroom switches ~150 mA on thin wires; the contact breaks the 40 A. Unchanged from the previous build, and still the reason the power run stays in the nose |
| Coil-sense opto (GPIO22) | **removed** | it only mattered while the logic survived the cut. With the ESP32 on the same relay there is nothing left to sense: no `MOTOR POWER` fault, no debounce, no bench jumper |
| Power latch (GPIO13) | **removed** | a firmware that can cut its own supply needs a priming button, a bootstrap rail, a FORCE ON switch and a "reboot = power-down" rule. A main switch does the same job with no failure modes and no code |
| Idle auto power-off | **removed with the latch** | it needed `POWER_HOLD`. A forgotten kart is now switched off by hand — the same hand that switched it on |
| Battery measurement (ADS1115 + divider) | **removed** | one 12 V pack, which is the motors' nominal voltage: nothing to cap automatically. Cost, stated: no LVC, no low-battery warning, no gauge — a flat pack is felt, not reported. The pack's own protection remains |
| Reverse-polarity protection | **the relay IS the gate: series diode in the coil** | the single relay feeds *everything*, so gating the coil gates the vehicle. A **series** 1N4007 makes the coil energize in one polarity only: reversed, nothing pulls in, nothing is powered, nothing blows — passive and repeatable. Considered and rejected: relying on the **flyback** diode alone (reversed, it shorts the coil and does keep the relay open, but it blows the fuse, exceeds its own rating, and vanishes silently if it ever fails open). Cost of the gate: one diode and ~0.9 V on a coil that has volts to spare |
| Arming button (GPIO16) | **removed** | arming already required a connected, calibrated gamepad holding its own START button, so the panel button duplicated a control the driver had in hand. Removing it takes the last GPIO input off the board and leaves nothing on the vehicle a bystander can press |
| Welded relay contact | **not detected, tested at commissioning** | the coil sense used to catch it in software. Now step 3 of the checklist (VB+ dead with the mushroom pressed) is the only test — deliberately accepted with the single-relay trade |
| Braking after the e-stop | **none — documented and measured** | with no power there is no electric brake of any kind. `arret_urgence_plat` puts a number on it (~15 m on the flat) so the behaviour is a known quantity rather than a surprise. NC relay across the phases stays the documented fix if ever wanted |

### 2026-08-02 review (previous build — kept for the record)

| Decision | Chosen then | Note |
|---|---|---|
| Hold capacitor | none | moot: there is no latch to hold up any more |
| Flyback on the 40 A coil | 1N4007 fitted | **kept**, and now doing double duty (see above) |
| Reverse-polarity guard | process, not parts | **superseded**: the coil diode backs the process up |
| Pre-charge on the contact | not fitted, watched | **still true** — the relay closes with the motors commanded off (boot sequence), so the make-current is the driver's capacitor inrush alone |
| Divider 100 k / 15 k | confirmed | **removed** with the ADC |
| Software bypass of the sense | removed (`pwr_sense_en` deleted) | moot: the sense itself is gone |
| Sense position | on the coil, not the relay output | moot: no sense |

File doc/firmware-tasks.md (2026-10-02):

# FreeRTOS tasks — priorities & core (ESP32, kart firmware)

ESP32 = **2 cores**: **core 0 = PRO_CPU** (network/system), **core 1 = APP_CPU** (application).
FreeRTOS at **1000 Hz**; priorities **0 (idle) → 24 (max)**, a **higher number = higher priority**.

## Application tasks (created by the firmware)

| Task | Priority | Core | Stack (B) | Period | Role | Source |
|---|:--:|:--:|:--:|---|---|---|
| **`control`** | **18** | **1** (APP) | 6144 | **500 Hz** | Control loop: gamepad state in, **A-button gate** (released = dynamic brake), pluggable **stick→motor mixing** (`mixer.hpp`), accel/decel ramps (`accel_pct_s` / `decel_pct_s`, the fall being the pseudo-freewheel), `duty_cap`, PWM/DIR out, arming state machine, event-log pushes (RAM ring only). **No sensor read** — no I²C, no ADC; **subscribed to the 2 s watchdog (PANIC)** | `controller.cpp` (`Controller::start`) |
| **`leds`** | **3** | **0** (PRO) | 3072 | ~20 Hz | Status display on the WS2812B strip (RMT) **+ event-log drain** (`evlog::maintain()`: RAM ring → flash, only while disarmed) | `leds.cpp` (`ledsStart`) |
| **`bt`** | **5** | **0** (PRO) | 8192 | (loop) | **BTstack / Bluepad32 loop**: Bluetooth stack, pairing and gamepad frames | `input_bp32.c` (`inputbp_start`) |

> **Why `control` sits at 18** (it started life at 6): it was raised when the loop still read
> the AS5600 wheel encoders — host-side Bluetooth work on core 1 preempted it long enough to
> stretch the interval between two reads past the sensor's ½-turn window, and the absolute
> angle aliased. The encoders are gone since 2026-09-29 and the loop reads no sensor at all;
> the priority stays, because it costs nothing and keeps the stick-to-motor latency independent
> of whatever else runs on core 1. 18 keeps the loop under only the system tier (esp_timer 22,
> Wi-Fi/BT 23, IPC 24), and it yields every cycle (`vTaskDelayUntil`), so it starves nothing.
> The `bt` task runs `btstack_run_loop_execute()` (blocking); the BT stack additionally
> creates its own system tasks (BT controller, BTC/BTU) on core 0.
> There is deliberately **no** dedicated event-log task: its first version cost 3 kB of stack
> on a heap-starved board — the LED task's 20 Hz loop hosts the drain instead.

## ESP-IDF framework tasks (created automatically, dependencies)

Values = **IDF defaults** (configurable in sdkconfig); listed to situate the relative priorities.

| Task | Priority | Core | Stack (B) | Role |
|---|:--:|:--:|:--:|---|
| `esp_timer` | 22 | 0 | 3584 | High-resolution timer callbacks — runs our **STA reconnection** (`sta_retry`) and the **history sampler** (`histSample`, 1 s, never blocks: try-lock only) |
| `wifi` | 23 | 0 | ~3584 | Wi-Fi stack (MAC) |
| `tiT` (lwIP / tcpip) | 18 | 0 | 3072 | TCP/IP stack (same number as `control`, but the other core) |
| `sys_evt` | 20 | 0 | 2304 | Default event loop (`esp_event`) — receives WIFI_EVENT / IP_EVENT |
| `httpd` | 5 | no affinity | **8192** | HTTP/WebSocket server (raised from the 4096 default after a stack overflow) |
| `mdns` | 1 | 0 | 4096 | mDNS responder (`kart.local`) |
| `main` | 1 | 0 | 3584 | `app_main`: subsystem init then exits |
| `ipc0` / `ipc1` | 24 | 0 / 1 | 1024 | Inter-core IPC (system) |
| `IDLE0` / `IDLE1` | 0 | 0 / 1 | 1536 | Idle tasks — **watched by the watchdog** (sdkconfig) |

## Notes

- The **network (Wi-Fi 23, tcpip 18, httpd 5)** lives on **core 0**, away from the control
  loop (core 1). A web request cannot delay the control loop — what CAN delay it (any task,
  any core) is a **flash write** (the cache suspends): that is why every NVS-writing verb
  (`set`, `wifiset`, calibration, pairing) is **refused while armed**, and why the event log
  drains to flash **only while disarmed**.
- The **Wi-Fi STA reconnection** (5 s after a drop, then doubling up to 5 min; postponed
  while armed) runs in the context of the `esp_timer` task (not a dedicated task).
- **Watchdog (TWDT, 2 s, `CONFIG_ESP_TASK_WDT_PANIC=y`)**: the `control` task re-arms it every
  cycle; a block > 2 s **reboots** (a warning would leave the motors on their last PWM). The
  idle tasks are watched too.

> **Source of truth for the application tasks: [`firmware/main/rtos.hpp`](../firmware/main/rtos.hpp)**
> (priority, core, stack as `constexpr` constants). The watchdog timeout lives in
> `sdkconfig.defaults` (`CONFIG_ESP_TASK_WDT_TIMEOUT_S`). Keep this table aligned with both.

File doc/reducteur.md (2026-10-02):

# Drivetrain (1:23.7) — motor pinion identification and gear train design

## Motor pinion (measured)

| Parameter | Value | Source |
|---|---|---|
| Number of teeth `z` | **16** | counted |
| Outside Ø `dₐ` | **19 mm** | caliper (even z → reliable direct measurement) |
| Tooth face width | **≈ 1/4″ (6.35 mm)** | measured — limits the USEFUL width of stage 1 |
| Apparent module | `m = dₐ/(z+2) = 19/18 ≈ 1.056` | calculation |
| **Identified standard** | **24 DP** (imperial diametral pitch) → `m = 25.4/24 = 1.058`; `dₐ = 18/24″ = 0.750″ = 19.05 mm` ✅ | deduction |
| Pressure angle | 20° (to confirm at meshing; 14.5° possible on old imperial gear teeth) | assumption |

**Variant to rule out/confirm by test**: metric module 1 with profile shift `x = +0.5`
(`dₐ = m·(z+2+2x) = 19 mm` too). Tie-breaker: apparent pitch `p = π·m` →
**24 DP: 3.33 mm** vs module 1: 3.14 mm; or print a 16T/24 DP test pinion
and check the tooth-in-tooth meshing with the motor pinion.

## ⭐ REVISION (chosen): 1:13.33 gearbox (16→80, 30→80) + 18T→32T #35 chain = **1:23.70**

> 🔁 **2026-09-29: gearbox-output sprocket 25T → 18T** — the owner's change, to slow the kart
> down for the children. Chain stage 1.28 → **1.778**, total 1:17.07 → **1:23.70**: top speed
> **×0.72** (simulated ~2.5 m/s loaded, was ~3.3), wheel torque **×1.39**. Everything in this
> revision is recomputed for the 18T; the 25T figures are quoted where the comparison helps.

| Mesh | Ratio | Center distance | Parts |
|---|---|---|---|
| **16T motor → 80T** | 5:1 | `96/48` = 2.0000″ = **50.80 mm** | 80T: pitch Ø 84.7, outside Ø **86.8 mm** |
| **30T → 80T (output)** | 2.667:1 | `110/48` = 2.2917″ = **58.21 mm** | 30T integral with the 1st 80T (compound gear) |
| **18T → 32T #35 sprockets** | 1.778:1 | **free** (chain cut to length) | 18 and 32 share a factor 2 — **not coprime** (see the wear note below) |

- **Total: 13.33 × 1.778 = 23.70** — ~2.6 m/s no-load on a 10″ wheel, **~2.5 m/s loaded
  (simulated)**, bounded only by `duty_cap`: nothing measures the speed since 2026-09-29.
  ×0.72 speed and ×1.39 wheel torque against the 1:17.07 of the 25T. The extra torque also
  brought a 16 % slope within reach of the dynamic brake (the kart creeps down at ~0.5 m/s
  where it ran away at 1:17.07).
- **Wear no longer spreads over every tooth.** 18 and 32 are both even, and the link count
  must be even too (below), so a given roller only ever lands on some of the teeth: with the
  60 links of the 165 mm layout, gcd(60, 18) = 6 → each roller meets **3 of the 18T's 18
  teeth**. The 25T (odd) spread wear over all of its teeth; a 17T or 19T would again. Minor at
  this duty — inspect the 18T for uneven tooth wear.
- ⚠️ **Higher loads at stage 2**: intermediate torque ×5 (1.8 N·m) → **Ft ≈ 113 N** on
  the 30T. At 20 mm thickness → ~22 MPa (ASA limit): **increase stage 2 to 25 mm** (~18 MPa).
- **Why a #35 roller chain and not a toothed belt** (belts abandoned for now): a chain is
  **cut to whatever length you need** — add or remove links, close it with a master link — so the
  gearbox-to-wheel **centre distance is a free variable** instead of being dictated by the stock
  belt lengths on the shelf. On a one-off build where the mount position settles during assembly,
  that is decisive. **#35** = 3/8″ (9.525 mm) pitch, roller/bushing Ø 0.200″, inner link width
  3/16″; **9.3 kN minimum ultimate** per ANSI, so roughly **1.2 kN working** (ultimate ÷ 8).
  Against an actual chain tension of **~175 N** (4.8 N·m at the gearbox output on the 18T's
  27.4 mm pitch radius; it was ~126 N on the 25T's 38 mm) that is a factor of **~7** — still
  far over-specified, which is fine. The **sprocket teeth** are another matter: see
  [what actually makes a printed sprocket strong](#what-actually-makes-a-printed-sprocket-strong).
- ⚠️ **The counterpart**: a chain does **not** damp shocks the way a belt does (they go straight
  into the gear teeth), it needs **lubrication**, and it needs **sprocket alignment + tension**
  kept up — slack chain climbs a sprocket flank and gets thrown. Budget an adjustable motor mount.
- ⚠️ **Sprockets are big**: at 3/8″ pitch the 18T is Ø 54.9 mm at the pitch line (Ø 59.7
  outside — the 25T was 76 / 81 mm), comfortably inside the 84.7 mm of the 80T gear next to it;
  the 32T still reaches **Ø 102 mm outside**. Check the housing and frame clearance. Generator
  parameters: see below.
- Firmware: **nothing to set** — `GEAR_RATIO` and `enc_per_wheel` went with the wheel encoders
  on 2026-09-29; the ratio only lives in the simulator (`VehicleParams::gear = 23.70`).
  Calculated alternatives on the same 32T: 19→32 = 1:22.5 and 17→32 = 1:25.1 (odd, so wear
  spreads over every tooth again); 20→36 = 1:24.0.

### Where to put the gearbox output sprocket

Chain layout

> Regenerable: `. .venv-schem/bin/activate && python doc/schematics/chain_layout.py`

**Never vertical.** With one sprocket directly above the other, gravity pulls the slack *along*
the run instead of into the teeth, and every millimetre of wear elongation accumulates at the
**bottom** sprocket where nothing holds the chain seated — it rides up the teeth and skips. Chain
makers all say the same: keep the line of centres **within 45° of horizontal** (60° absolute
maximum, and then only with a tensioner).

**The constraint is the distance, not the direction.** Any position on a circle of radius C around
the wheel axle works, as long as it stays out of the two vertical 45° sectors. That is a lot of
freedom for dodging a frame member — the gearbox can go forward, back, or diagonally up.

18T → 32T, `L = 2C/p + (N1+N2)/2 + ((N2−N1)/(2π))² · p/C` rounded up to an even count; wrap on
the small sprocket at the nominal C:

| entraxe C | links (even) | C that fits exactly | wrap on 18T | slack at 1 % |
|---|---|---|---|---|
| 130 mm | 54 | 136.5 mm | 161.3° | 1.3 mm |
| 150 mm | 58 | 155.7 mm | 163.8° | 1.5 mm |
| **165 mm** | **60** | **165.3 mm** | **165.3°** | **1.7 mm** |
| 180 mm | 64 | 184.5 mm | 166.5° | 1.8 mm |
| 300 mm | 90 | 308.8 mm | 171.9° | 3.0 mm |

- **Swapping 25T → 18T on the 165 mm mount takes the chain from 64 to 60 links** (165.3 mm fits 60
  exactly). The old 64-link chain would need 184.5 mm — outside the ±15 mm slot — so take four
  links out rather than moving the gearbox.
- **A short centre distance costs almost nothing here.** The 30–50 pitch guideline is written for
  fast, heavily loaded industrial drives. This chain runs at **~1.0 m/s** (1.3 with the 25T) and
  **15 % of its working load** (175 N of 1200 N). Going from 300 to 150 mm multiplies articulations
  per km by 1.5 — noise at that duty. Wrap stays above 160° throughout: less than the 25T's 170°+
  (the two sprockets are further apart in size now), still far above the ~120° usually quoted as
  the minimum on the small sprocket.
- **What a short centre distance really costs is tension sensitivity**: 1.7 mm of nominal slack is
  hard to set by eye, and 1 % of elongation on a 572 mm (60-link) chain is 5.7 mm — a large
  relative change. You will re-tension more often. That is the whole trade.
- **Even link count is mandatory**: an odd count needs a cranked offset link, roughly 20 % weaker.
- **Slack ~1 % of C, not the usual 2 %** — reverse is always allowed on this kart, so both runs take
  turns being the tight side and there is no permanent slack side to be generous with.
- **Slot the mount ±15 mm**: two links quantise the centre distance in ~9.5 mm steps, and 3 % of wear
  elongation on a 572 mm chain moves it another ~9 mm.

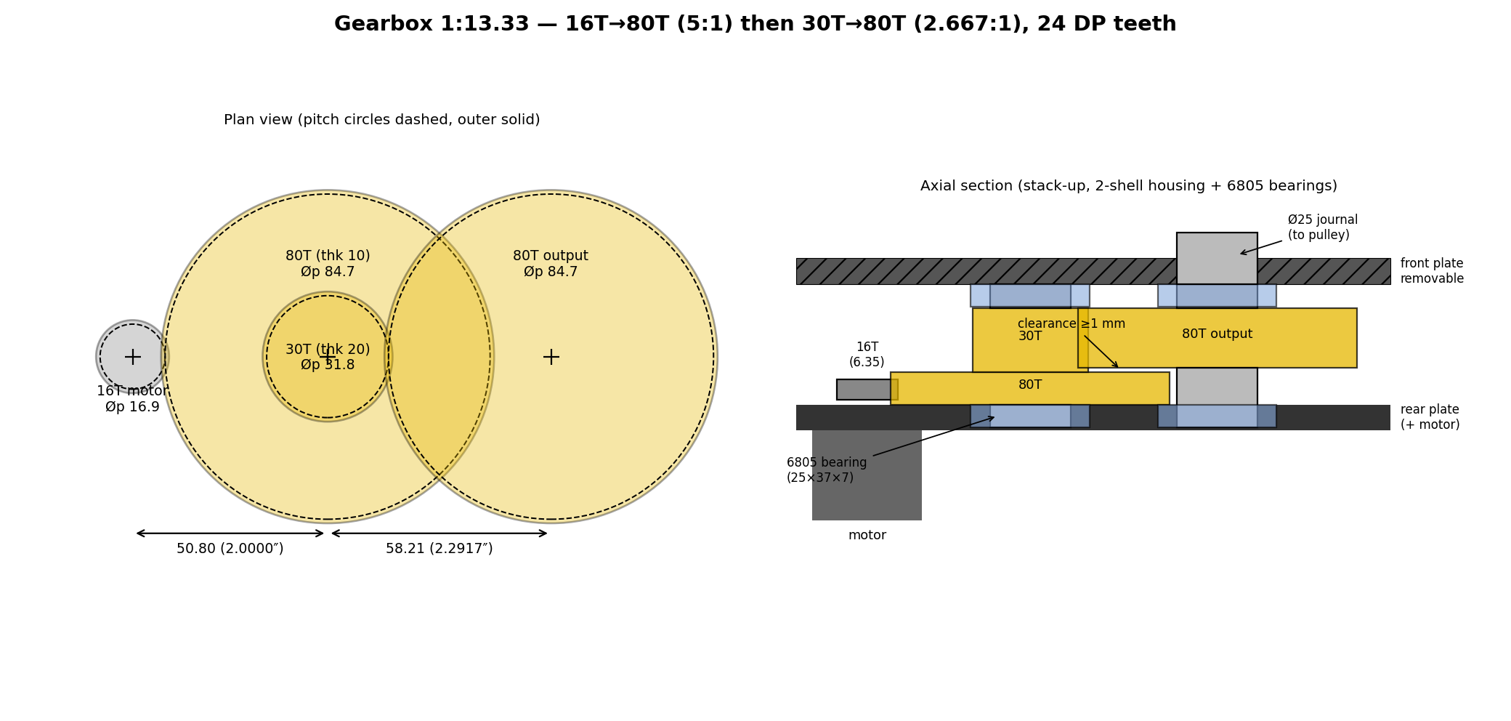
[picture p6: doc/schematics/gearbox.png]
Gearbox schematic


> Regenerable: `. .venv-schem/bin/activate && python doc/schematics/gearbox.py`
> (plan view at the real center distances + axial section of the stack).

**Parametric 3D model**: [`doc/cad/gearbox.scad`](cad/gearbox.scad) (OpenSCAD, standalone —
involute gear-tooth generator included, revision dimensions as parameters).
`part` selector: `assembly` / `compound` (80T+30T) / `output` / `back` / `front` /
`pinion_test` (16T test pinion to validate the 24 DP) → direct STL export.

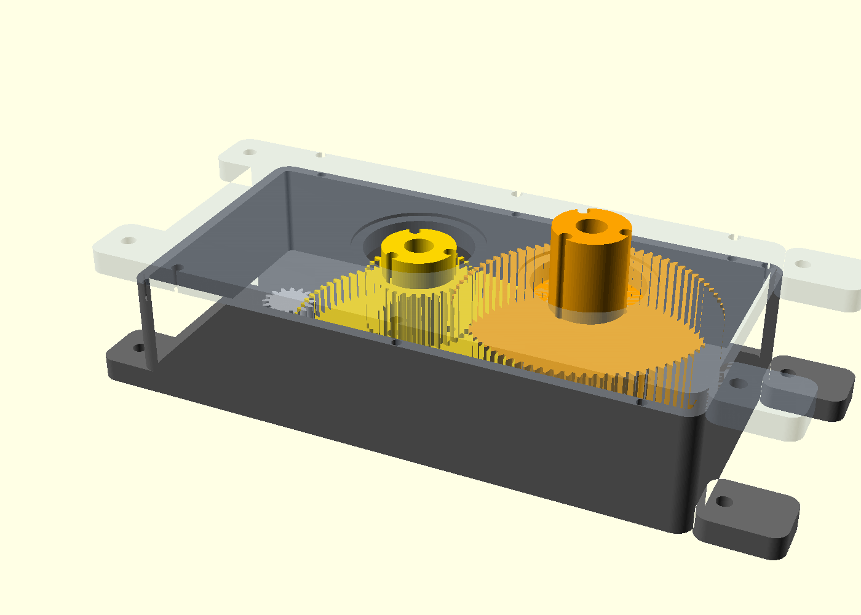
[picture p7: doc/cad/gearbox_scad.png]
OpenSCAD render


### PETG print profile — gears (validated)

Settings that finally printed the gears cleanly after chasing a recurring extruder jam
(all-metal hotend):

- **Nozzle 260 °C, first layer also 260 °C** (0.4 mm nozzle, 0.12 mm layers). Do **not**
  lower the first-layer temperature — a cooler, more viscous first layer raises back-pressure
  and jams. A little stringing at 260 °C is purely cosmetic on a gear; peel it off / clean
  the tooth flanks.
- **Heatsink (hotend) fan at 100%** the whole time.
- **Enclosure open** (validated on an enclosed printer with the lid removed). PETG needs no
  chamber, and a warm enclosure made the jamming worse (heat creep + hotter extruder motor).
- **≥ 5 perimeters** (solid teeth), **gyroid infill**, printed **flat** (gear face on the
  bed) so the tooth-bending load runs in-plane with the layers, not across them.
- **One gear per plate** — fewer travel moves = fewer retractions (a heat-creep contributor).
- **Retraction 1 mm @ 35 mm/s** (validated, direct-drive extruder) — short and slow so the
  soft PETG is pulled, not ground; Bowden setups need more (~4 mm).
- **Filament dry** (PETG is hygroscopic) and at the correct 1.75 mm diameter.

> Diagnostic note: the jam was **thermal/flow**, not mechanical. Ruled out along the way —
> moisture (fresh vacuum-sealed spool), a nozzle clog (clean cold pull), and oversized
> filament (measured). It was cured by **more heat (260 °C) + maximum heat-break cooling +
> an open chamber**, not by lowering the temperature.

> ⚠️ That profile is tied to **that** printer — an open-frame machine whose all-metal hotend
> was heat-creeping. "Open the enclosure, push to 260 °C" is the cure for that fault, **not**
> a general PETG rule. Do not port it onto an enclosed machine (see the K1 Max profile below,
> which runs happily at 255 °C with the chamber at 35 °C).

### Sprocket generator parameters (CAD add-in) — #35, both sprockets

The "Create Sprocket" dialogs default to **#40**, whose pitch and roller are both wrong for
this build. Four numbers, and only the tooth count changes between the two sprockets:

| Field | 18T (gearbox output) | 32T (wheel) | Why |
|---|---|---|---|
| Chain Pitch | **0.375 in** | **0.375 in** | #35 = 3/8″ = 9.525 mm (#40's 0.50″ is the usual wrong default) |
| Number Of Teeth | **18** | **32** | 1.778:1 (the gearbox side was 25T until 2026-09-29); both even → see the wear note above |
| Roller Diameter | **0.200 in** | **0.200 in** | #35 roller Ø (#40 is 0.313″) |
| Sprocket Thickness | **0.170 in** | **0.170 in** | 4.32 mm — must fit between the inner link plates (**4.76 mm**); 0.25″ = 6.35 mm does NOT |

Check the generated body against these before printing — if the pitch was ignored, the
diameters give it away immediately:

| | pitch Ø `p/sin(180°/N)` | outside Ø `p·(0.6 + cot(180°/N))` | tooth-root Ø (pitch Ø − roller) |
|---|---|---|---|
| **18T** | **54.9 mm** | **59.7 mm** | 49.8 mm |
| 32T | **97.2 mm** | **102.4 mm** | 92.1 mm |
| *25T (previous)* | *76.0 mm* | *81.1 mm* | *70.9 mm* |

The 0.170″ thickness is not a rounded guess: it is **18 layers × 0.24 mm exactly** in the
profile below, leaving 0.44 mm of clearance inside the link plates. Both sprockets print with
that same profile — the 18T changes only the tooth count, not pitch, roller or thickness.
✅ **32T printed and verified meshing with the real #35 chain (2026-08-05).**

### PETG print profile — #35 sprockets (Creality K1 Max) — 25T and 32T printed

| Setting | Value |
|---|---|
| Nozzle / bed / chamber | **255 °C** (first layer too) · 70 °C · 35 °C |
| Layer height | **0.24 mm** (first layer 0.20), 0.4 mm nozzle |
| Walls | **5 loops**, 0.42 mm, inner→outer |
| Top / bottom shells | 5 / 5 |
| Infill | 40 %, **triangles** |
| Flow ratio | 0.95 · max volumetric **9 mm³/s** |
| Elephant-foot comp. | 0.15 mm · brim **ears**, 5 mm |
| Retraction | 0.8 mm @ 40 mm/s, z-hop 0.4 mm |

Used as-is for both the 25T and the 32T. Three things worth knowing before reusing it:

- **The teeth come out 100 % perimeter, by accident and happily.** A #35 tooth is ~4–5 mm
  across and 5 walls give 2.1 mm of solid from each side = 4.2 mm. Nothing is left for the
  infill to fill, so the infill pattern only matters for the hub and web. This is exactly the
  property you want on a tooth and it is why 40 % triangles is fine here even though the gears
  wanted gyroid.
- **The headline speeds are fiction** — the 9 mm³/s volumetric cap governs everything:

  | | profile says | actually prints at |
  |---|---|---|
  | outer wall | 200 mm/s | **89 mm/s** |
  | inner wall | 300 mm/s | 83 mm/s |
  | infill | 250 mm/s | 83 mm/s |

  Not a problem (slow and cool suits PETG), but do not go tuning those numbers expecting
  anything to change until the volumetric cap moves.
- **Thickness quantises to 4.08 or 4.32 mm** (17 or 18 layers for a 4.27 mm tooth). Both clear
  the 4.76 mm inner link width, so either is fine — but check which one you got before
  blaming the chain if it binds.

⚠️ **Print it FLAT** (face on the bed): the tooth-bending load then runs in the plane of the
layers instead of across them. Same rule as the gears, and it matters more here — the chain
loads one tooth at a time.

⚠️ `xy_hole_compensation` is **0** in this profile, so the bore prints undersize by the usual
0.1–0.2 mm. Measure the shaft fit on the first part rather than assuming nominal.

### What actually makes a printed sprocket strong

Short version: **infill is not what you think it is, and it is not what breaks.** Two parts of
the sprocket carry load, and they are carried by different settings.

**The web carries torque from the bore out to the rim** — that is the only job the infill has.
Treating it as a thin disc in torsion (4.32 mm thick), at 4.8 N·m of gearbox output torque —
the same torque whatever the tooth count, so the same numbers as on the 25T; the 18T's web is
simply shorter, its tooth root sitting at r ≈ 24.9 mm:

| radius | shear in the web |
|---|---|
| 12.5 mm (at the bore) | 1.13 MPa |
| 20 mm | 0.44 MPa |
| ~25 mm (18T tooth root) | 0.29 MPa |

PETG takes 12–15 MPa. So the web is over-strength by a factor of **ten or more even at 40 %
infill** — and at 5 top + 5 bottom shells out of 18 layers, the part is 73 % solid by thickness
anyway. **Raising the infill density buys nothing here.** If you ever want a stronger sprocket,
that dial is not the one.

**The teeth carry the chain, and they are already 100 % perimeter.** A #35 tooth is ~4.8 mm
across; five 0.42 mm walls give 2.1 mm of solid from each side = 4.2 mm. The infill never
reaches a tooth. What sets tooth strength is the **wall count** and, far more, the **print
orientation**.

Root bending, with the ~175 N chain tension of the 18T (same #35 tooth section, scaled by the
tension; the 25T's ~126 N gave 16.4 / 8.2 / 5.5 MPa):

| teeth sharing the load | stress at the root |
|---|---|
| 1 | **22.7 MPa** — **over** the PETG allowable (12–15 MPa) by half again or more |
| 2 | 11.4 MPa — at the allowable |
| 3 | 7.6 MPa |

Which is the real reason the earlier warning about **chain tension and sprocket alignment**
is not housekeeping advice: with proper wrap about eight teeth of the 18T are engaged (165°) and
the first few share the pull, but a slack or misaligned chain rides up and dumps the whole
175 N onto **one** tooth. On the 25T that was at/over the limit; on the 18T it is **clearly
over it**. That is how a tooth shears off — so with the 18T, tension and alignment are no
longer margin, they are what keeps the teeth on. The 32T carries 175 N × 48.6 mm ≈ 8.5 N·m
(6.1 before) — ~2 MPa of web shear even at a 12.5 mm radius, still far inside PETG's.

Ranked, what changes the strength of this part:

1. **Print orientation — flat, face on the bed.** Worth a factor of 2–3 on its own. Printed on
   edge, the tooth-bending load pulls layers apart and the teeth snap. Nothing else on this
   list can compensate for getting it wrong.
2. **Wall count.** 5 loops is what makes the teeth solid. Below 4 the tooth core turns to
   infill and the numbers above stop applying.
3. **Interlayer bonding** — nozzle temperature, and *how hard you cool*. This profile runs the
   part fan at **80–90 %**, which is a lot for PETG: it buys crisp tooth edges and costs Z
   strength. Printed flat that is a fair trade (the load is in-plane), but it is the setting to
   revisit first if a tooth ever delaminates rather than breaks.
4. **Flow.** 0.95 is slightly under-extruded; voids between beads are missing cross-section.
   1.0 is the strength setting, 0.95 the dimensional-accuracy one.
5. **Seam placement.** `seam_position: aligned` stacks every perimeter's start point into one
   vertical column. On a gear, check where that column lands — a seam sitting in a tooth root
   is a crack starter in the worst possible place. Random or scarf spreads it.
6. **Infill density and pattern** — last, and by a wide margin, for the reasons above.

#### Top / bottom shells: the part is a sandwich

The 5 + 5 solid layers are not "surface finish", they are the **skins of a sandwich** and the
infill is its core. Skins carry bending, core carries shear — and because plate stiffness goes
as thickness cubed, the skins dominate:

| | thickness | share of out-of-plane bending stiffness |
|---|---|---|
| 2 skins (5 layers each) | 1.20 mm × 2 | **91 %** |
| 40 % core | 1.92 mm | 9 % |

So if the sprocket ever needs to resist being **bent sideways** — a misaligned chain pulling
the rim out of plane, or the part doubling as a flange — **add shell layers, not infill**. Same
material, an order of magnitude more effect. Note this applies to the web only: a tooth is
solid perimeter on every one of its layers, so the shell count changes nothing there.

#### Layer height: matters less than it looks, but pick it deliberately

Printed **flat**, the tooth profile is an XY contour repeated identically on every layer, so
layer height does **not** degrade the tooth shape — that is set by line width, `resolution`
and arc fitting. What it does change:

| layer height | layers in 4.32 mm | interfaces | thickness you actually get |
|---|---|---|---|
| 0.12 mm | 36 | 35 | 4.32 mm |
| 0.20 mm | 21.6 | ~21 | 4.40 mm |
| **0.24 mm** (this profile) | **18** | **17** | **4.32 mm** |
| 0.30 mm | 14.4 | ~13 | 4.20 mm |

- **Thickness quantisation.** 0.24 lands exactly on 4.32 mm, which is why it is a good choice
  here. 0.20 overshoots to 4.40 — still inside the 4.76 mm inner link width, but less margin.
  Always check the thickness your layer height actually produces before printing a sprocket.
- **Interface count.** Thicker layers mean fewer planes that can delaminate. Irrelevant while
  the load stays in-plane (flat print), useful insurance when it does not.
- **In-plane strength is essentially unaffected** — each layer carries its share in proportion
  to its height, so the total is the same. Choosing 0.12 over 0.24 buys print time, not teeth.

The one place layer height genuinely costs you is the **top and bottom faces of the teeth**,
where the chain plates run: 5 shells at 0.24 mm give a 1.2 mm skin, at 0.12 mm only 0.6 mm.
Keep the shells as a **thickness**, not a layer count, if you change layer height — 10 layers
at 0.12 mm to keep the same 1.2 mm skin and the same 91 %.

---

## Previous iteration (reference): printed 1:8 gearbox + 1:2 belt to the wheel (= 1:16)

> ⛔ **Superseded.** Kept for the sizing work only — the belt was dropped in favour of the
> #35 chain (free length, see the revision above). The shock-absorption argument below is
> what a belt would have bought us; the chain does not offer it.

Same total reduction (~3.2 m/s on a 10″ wheel), but the **last stage — the most loaded — becomes the
belt** (absorbs shocks, quiet, tolerant of alignment): the gearbox now sees
only ~2.9 N·m at the output instead of ~5.8 N·m.

**Chosen 1:8 gearbox — all in 24 DP** (reuses the 64T design):

| Mesh | Ratio | Center distance | Parts |
|---|---|---|---|
| **16T motor → 64T** | 4:1 | `80/48` = 1.6667″ = **42.33 mm** | printed 64T (outside Ø 69.9 mm), 10 mm thick — USEFUL width limited by the motor pinion (6.35 mm) → ≈15 MPa, OK; the 10 mm give ±1.8 mm of axial alignment tolerance |
| **32T → 64T (output)** | 2:1 | `96/48` = 2.0000″ = **50.80 mm** | 32T **integral with the 1st 64T** (compound gear); output 64T identical to the 1st |

- The **32T** (outside Ø 36.0 mm) is glued/fused to the stage-1 64T → a single compound
  gear on the intermediate shaft; the gearbox output carries the 2nd 64T + the pulley.
- **Ø25 journal compatibility** (25×37 bearings): 32T root Ø = **31.2 mm** →
  OK **only as a one-piece printed journal** (monolithic). ⚠️ Do NOT bore the 32T
  to 25 for a through-axle (3 mm of wall under the teeth, no room for a key).
  On the output side, no problem (64T root = 65.1 mm).
- **Flange/journal assembly: 3 screws on a bolt circle + central pilot**
  (chosen): the 3 screws precompress the layers (FDM anti-delamination) and transmit the
  torque (~30 N/screw at ~15 mm radius — very generous); the **central bore acts as an alignment
  pilot**: tight fit (+0.05/+0.1) and **≥ 5 mm of engagement** to guarantee
  concentricity AND perpendicularity (any warp = irregular meshing once/rev). Heads and
  nuts in counterbores/hex pockets + washers, nylock, retighten after break-in (creep); check
  that nothing protrudes into the adjacent gear-tooth plane (the overlap zone of the two 64T).
- **Thicknesses (Lewis calculation, motor τ 0.36 N·m, driver limited to 20 A, ASA allowable 15–20 MPa,
  velocity factors + plugging-brake jolts included)**:
  | Gear | Thickness | Peak stress |
  |---|---|---|
  | 16T motor (metal) | 6.35 mm (imposed) | — (sets the useful width of stage 1) |
  | 64T stage 1 | **10 mm** (12 if alignment margin desired) | ~18–20 MPa over the 6.35 useful — thickening it changes nothing |
  | 32T | **20 mm** | ~16 MPa (Ft ≈ 80 N) |
  | 64T output | **20 mm minimum** (22 = alignment margin) | ~13 MPa; ⚠️ useful width of stage 2 = min(32T, 64T) — at 15 mm the 32T rises back to ~21 MPa |
- Motor→output footprint: 42.33 + 50.80 ≈ **93 mm** (axes foldable at an angle).
- **Break-in & lubrication**: (1) **dry** break-in 10–15 min unloaded, low speed — the
  layer ridges polish themselves, the dust falls off (greasing too early = abrasive paste);
  (2) **clean** the dust; (3) **thin layer** of **PTFE or silicone** grease on the
  tooth flanks (no bath; lithium tolerated, **never** any penetrating oil/solvent on the ASA);
  (4) after a few hours: retighten the flange screws (creep), check for wear.
  6805 bearings greased for life. ⚠️ With the #35 chain the opposite rule applies on the output side: the **chain must stay lubricated** (chain oil on the rollers, wiped off the outside) — only the *gear* flanks take PTFE/silicone.
- **2-part housing**: main shell + **removable plate** (insert the gears
  then close). Plate requirements: **2 centering dowels** (screws alone have play →
  the center distance must repeat to ~0.1 mm), **shouldered** bearing seats (captive with the plate
  screwed on), thickness ≥ 6–8 mm or ribbed, heat-set threaded inserts on the shell side.
- **Material: ASA** (chosen if printing allows) — nozzle 240–260 °C, bed 90–110 °C,
  **enclosure almost indispensable**, ventilate (styrene), **shrinkage ~0.4–0.7%** → a test jig
  to calibrate the dimensions (Ø37 seats, Ø24.9 journals, gear teeth).
- **Materials comparison** (decisive criterion: temperature — friction + closed housing + summer):
  | | Tg | Hot fatigue allowable | Gear verdict |
  |---|---|---|---|
  | **ASA** | ~100 °C | 15–20 MPa | ✅ **final choice** (UV + heat + creep); weak inter-layer bonding offset by the 3 screws |
  | **PETG** | ~80 °C | 12–15 MPa | 🟡 fallback without an enclosure: thicken stage 2 to **22–25 mm**, retighten the screws (creep), slightly faster wear |
  | **PLA** | ~58 °C | 5–8 MPa at 50 °C | ❌ **prototypes only** (accurate and fast to validate center distances/meshing) — softens in summer, creeps at standstill, teeth that chip |

*Alternatives studied: single stage 16T→128T (center distance 76.20 mm, Ø137.6 wheel) or a 2nd stage in
module 2 (15T→30T, center distance 45 mm) — ruled out in favor of reusing the 64T.*

**1:2 belt**: tooth ratio **exactly 2:1** (e.g. HTD 5M synchronous: gearbox pulley
30T Ø47.7 → wheel pulley 60T Ø95.5, screwed onto the 12″ rim). Useful tension ≈ 100 N at max
torque — very comfortable for a 15 mm belt.

> 🗄️ *Historical: the firmware used to carry `hw::GEAR_RATIO = 1.28` and `WHEEL_DIAM_M = 0.254`
> for the AS5600 magnet on the gearbox output (vehicle speed = signed average of the two
> wheels). The wheel encoders were removed on 2026-09-29; nothing in the firmware depends on
> the gearing any more.*

---

## Initial train (reference): 2 stages of 4:1 (= 1:16), 1:1 belt

> ⛔ **Superseded** (belt abandoned — see the revision at the top).

```
Motor ──[16T metal, 24 DP]──╮
                            ├─ Stage 1 (4:1) ─→ intermediate shaft ──[15T]──╮
                 [64T printed]                                              ├─ Stage 2 (4:1) ─→ wheel
                                                                 [60T printed]
```

The 64T (stage 1) and the 15T (stage 2) are **integral** (compound gear, printed as one piece).
Only stage 1 must match the motor pinion; stage 2 is free → **module 2** (4× higher
torque = larger teeth).

### Stage 1 — 16T (metal) → 64T (printed)

| Parameter | Value (24 DP) | Module 1 + profile shift variant |
|---|---|---|
| Module / angle | 1.058 mm (24 DP), 20° | m = 1, wheel generated with x = −0.5 |
| **Center distance** | **42.33 mm** | **40.00 mm** |
| 64T wheel outside Ø | ≈ 69.9 mm | ≈ 67 mm |
| Tooth face width | 10–12 mm (≥ motor pinion) | same |
| Form | spur (imposed by the metal pinion) | same |

### CAD parameters entered — stage-1 64T wheel (spur gear generator)

| Field | Entered value | Metric equivalent |
|---|---|---|
| Standard | **English** | — |
| Pressure Angle | **20 deg** | 20° |
| Diametral Pitch | **24** | module 1.058 mm |
| Number of Teeth | **64** | — |
| Backlash | **0.1 mm** | print clearance |
| Root Fillet Radius | 0.000 in | ⚠️ see note |
| Gear Thickness | 0.394 in | **10.0 mm** |
| Hole Diameter | 0.394 in | **10.0 mm** (bore) |
| Pitch Diameter (computed) | 2.7 in (= 64/24 = 2.667″) | **67.7 mm** pitch → outside Ø 69.85 mm |

> ⚠️ **Root Fillet Radius = 0**: zero tooth-root fillet = stress concentration at the
> root (where a printed tooth breaks). Set a small value (e.g. **0.012 in ≈ 0.3 mm**)
> if the generator accepts it — free in 3D printing and much stronger.

### Stage 2 — 15T → 60T (printed, module 2)

| Parameter | Value |
|---|---|
| Module / angle | 2 mm, 20° |
| **Center distance** | **75.00 mm** |
| 15T / 60T outside Ø | 34 mm / 124 mm |
| Tooth face width | 15 mm |
| Form | **herringbone (chevrons)** recommended — printable, quiet, self-centering |

### Sizing (orders of magnitude)

- Motor torque ≈ 0.36 N·m (172 W @ 4615 rpm) → intermediate ≈ 1.4 N·m → **~95 N**
  tangential on the 15T → ≈ 13 MPa at the tooth root (Lewis, m2 × 15 mm) → margin ≈ ×3 in
  **PETG** (nylon even better for the 15T). The driver limits to 20 A → no excessive stall
  torque.
- Output: 4615/16 ≈ 288 rpm at 12 V; **~240 rpm at 50% PWM → ~3.2 m/s (11.5 km/h)** on a 10″ wheel.

### Printing / assembly

- **Backlash +0.10–0.15 mm** in the generator for all printed parts.
- 100% infill or ≥ 6 perimeters.
- **Chosen bearings: 6805 — 25×37×7 mm (thickness confirmed)** → housing seats
  **7 mm** deep, shouldered.
  Assembly: bearings **seated in the housing walls**; the 64T+15T compound gear is
  printed with **integrated Ø25 journals** on each side that turn inside them.
  - ⚠️ Impossible to seat the bearing **inside** the 15T (root Ø ≈ 25 mm < the bearing's
    37 mm outside Ø) → it is indeed the axle that turns, not the bearing inside the gear.
  - Housing seat: Ø **37.1–37.2 mm** (printed fit), shouldered, depth = bearing
    thickness; journal Ø **24.9 mm** (slight interference in the inner race).
  - The 10 mm bore entered in the 64T CAD becomes useless with the integrated journals
    (or serves as a central passage if you prefer a through-axle).
- Motor→output footprint: 42.33 + 75 ≈ **117 mm** total center distance.
- Validation order: 16T/24 DP test pinion → stage 1 alone → complete train.

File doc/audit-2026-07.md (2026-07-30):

# Firmware audit — July 2026

Requested after the ADS1115 incident: find the other flaws of the same families —
peripherals able to stall the 500 Hz loop, failure modes that return valid-looking
values, and fixed buffers whose guards don't actually guard. Every `.cpp/.hpp` under
`firmware/main/` was read end to end; everything reachable from the control task was
traced (I2C, mutexes, NVS, logging), every sensor-failure return path checked for
sentinel values, every static buffer checked against the bound its guard claims.

## Fixed (commit of 2026-07-30)

| # | Flaw | Family |
|---|---|---|
| 1 | **Recalibrating while armed left the kart drivable.** The wizard tells the driver to push both sticks to their stops — with the kart armed those sweeps were live full-throttle commands. `input::calibrated()` now reports false during collection (→ blocking NOCAL → disarm + brake, re-arming refused until the wizard ends) and `input::get()` zeroes the calibrated axes for the same window. | safety |
| 2 | **The blue "calibration" LED was dead code.** `State::Calibrate` exists in the enum but nothing ever produced it. The strip now derives blue directly from `input::calState()`, and it outranks the red fault blink that fix #1 deliberately raises during collection. | silent failure |
| 3 | **The history guard checked the wrong buffer.** `HIST_PB_MAX` was static-asserted against the 10 240-byte reply arena, but Hist encodes into its own 1 024-byte cache — a guard that could never fire, in front of an encode that fails silently (charts just stop). Now asserted against `HIST_BIN_CAP`. | guard mismatch |
| 4 | **Two readers stole each other's loop-time peaks.** `loopMaxUs()` is reset-on-read and had two consumers (the 5 s history slots and the System-tab poll): with the System tab open the worst-tick chart under-reported. One peak slot per consumer. | measurement lies |
| 5 | **NVS writes could land while armed.** A flash write suspends the cache and freezes the control loop for tens of ms. First fix: `wifiset` refused while armed (the `set` path deferred to the disarm edge). Follow-up the same day: **every** NVS-writing verb — `set`, `calstart`, `padpair`, `padunpair` — is now refused while armed, and the deferred-flush machinery (`configFlushPending`, the control task's disarm-edge NVS write) was removed outright. Nothing writes flash while driving, full stop; the page greys the buttons out. | loop stall |
| 6 | **Oversized WebSocket frame desynced the socket.** A frame > 1 024 B was "handled" by returning OK with the payload left unread — httpd then parsed those bytes as the next frame header. Now the socket is closed (verified live: client reconnects clean). | protocol |
| 7 | **Low-battery orange lied when the voltage was unknown.** Telemetry reports 0 V while the ADS1115 is silent, which is below every warn threshold — the strip claimed "low battery" when the truth was "no reading". Gated on `vbat > 0`. | sentinel value |
| 8 | **IPv6 array sized by hope.** `esp_netif_get_all_ip6` fills up to `LWIP_IPV6_NUM_ADDRESSES` entries with no cap parameter; the buffer was a hard-coded `[5]` over a config of 3 — a silent stack overflow the day the sdkconfig is raised. Sized by the config macro. | unbounded buffer |

Plus a stale comment in `ads1115.cpp` that still said the shared I2C timeout was 4 ms.

## Checked and accepted as-is

- ~~`configFlushPending()` runs in the control task on the armed→disarmed edge~~ —
  initially accepted (a flash write freezes every flash-resident task regardless of which
  one issues it, and it only ever ran disarmed), then **removed entirely** the same day:
  since `set` is now refused while armed there is nothing left to defer, and the control
  task no longer touches NVS at all. `configUpdate` still persists while holding the config
  mutex, but it is only reachable disarmed.
- **Telemetry `vbat` is 0.0 (not −1) while unknown.** The page and the LED strip both gate
  on the NO_VBAT bit / `vbat > 0`, so nothing downstream mistakes it for a reading anymore;
  the battery history dropping to 0 during an outage is visible rather than misleading.
- **Torn string reads** (`m_name`, `m_sta_ip`): written by one task, read by another with no
  lock. Worst case is one garbled *display* string for one frame; both are bounded and
  null-terminated. Not worth a mutex on the status path.
- **Stuck-wheel detection is blind during a pure pivot** (mean of the two outputs ≈ 0). By
  design: the per-wheel reversal and aberrant-speed checks stay armed and cover it.
- **`reboot` is honored while armed.** It is an explicit human action, equivalent to the
  power switch, and the motor pins fall back to dynamic braking through the external
  pull-downs (see README on reset behaviour). Refusing it would remove a legitimate remote
  kill while adding no safety.
- **Worst observed tick on the bench is 2.4–9.5 ms against the 2 ms budget** with one
  encoder unplugged (wall clock, includes Wi-Fi/BT preemption; I2C cost alone 1.7–3.4 ms).
  The aliasing ceiling is 94 ms, so the margin is ×10 even at the worst peak; the loop
  chart on the Dashboard now makes any drift visible.
- **The heap is the scarcest resource on this board — treat every static kilobyte as spent
  heap.** The event log's first version proved it: a 3 kB task stack plus ~4 kB of static
  buffers dropped idle heap from ~19 kB to 12 kB and the page visibly choked (a 6.5 kB
  config frame timed out mid-send, `heap_min` bottomed at 848 B under a real page load).
  The follow-up RAM audit (2026-07-31) then found where the real fat was and cut 31.5 kB
  of static DRAM + ~6 kB of Wi-Fi heap: BTstack's HCI ring sized for BNEP/PAN throughput
  (20×1 kB ACL + 10 SCO *audio* buffers, for a gamepad sending 80-byte reports — 22.3→7.2 kB,
  flow control makes the cut safe by design), Bluepad32's table of 4 gamepads for a 1-gamepad
  kart (4→2), the 10 kB protobuf arena (→8 kB), the evlog reply buffer (now streamed straight
  from flash), Wi-Fi static RX 10→6 and TCP buffers 5760→2880 (chart.js still serves in
  0.5 s). New baseline: **~52 kB free at idle, ~36 kB minimum under a worst-case page load.**
  Rule of thumb: after ANY feature, check idle `heap_free` (expect ≥ 45 kB now) and re-run
  the two-client soak.

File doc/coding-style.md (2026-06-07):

# Coding Style Guide

This document outlines the coding style for the `oe-heatgrip-gdo` projects.

## Variable Naming

- **Local variables**: Use `snake_case`.
- **Global variables**: Use `g_snake_case`.
- **Member variables**: Use `m_snake_case`.
- **Functions**: Use `lowerPascalCase` (camelCase).
- **Constants and Macros**: Use `UPPER_CASE`.
- **Classes/Structs**: Use `PascalCase` (e.g., `struct MessagePacket;`).
- **Enums**: Use `enum class` (scoped enums) with `PascalCase` members (e.g., `enum class DeviceState { ... };`).
- **Acronyms**: Keep acronyms in uppercase (e.g., `OTA`, `GDO`, `PMK`, `SSID`, `WAP`, `PWM`).
- **Brackets**: The starting brace `{` **MUST** be on a new line (Allman style).

### Type Prefixes (Hungarian Notation)

> [!IMPORTANT]
> **DO NOT** use prefixes linked to the type in variable names.
>
> - **Incorrect**: `bool b_is_active`, `uint32_t u32_count`, `char* sz_name`, `void* p_data`.
> - **Correct**: `bool is_active`, `uint32_t count`, `char* name`, `void* data`.

## Const Correctness

- **Always mark a variable `const` if it never changes after initialization.** This applies to local variables, parameters passed by reference/pointer, and member functions that don't mutate state.
  - **Correct**: `const int count = readCount();`, `const KartConfig cfg = configSnapshot();`, `void print() const;`.
  - **Incorrect**: `int count = readCount();` when `count` is never reassigned.
- Prefer `constexpr` over `const` for values known at compile time.

## Conditions

- **Yoda conditions**: Place the constant on the left side of comparisons to prevent accidental assignment.
  - **Correct**: `if (0 == getValue())`, `if (ESP_OK == esp_init())`.
  - **Incorrect**: `if (getValue() == 0)`, `if (esp_init() == ESP_OK)`.

## Project Structure

- Source files should use the `.cpp` extension.
- Namespaces should be used to group related functions and variables (e.g., `HardwareGPIO`, `Settings`, `WebServer`, `MemBlock`).

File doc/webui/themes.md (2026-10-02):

# Web UI themes (skins)

The on-board web UI ([`firmware/main/assets/`](../../firmware/main/assets/)) keeps
its **layout and behaviour** in the bulk of `style.css` / `index.html`, and its
**look** (colours + a few flourishes) in a single, clearly delimited block at
the bottom of `style.css`:

```
/* ===== THEME: … (active skin — everything above is structure) ===== */
```

Switching skins is therefore a **one-block replace**: delete that block and
paste one of the blocks below. Nothing else changes — the ids/classes the
JavaScript drives (`fd-*`, `#ind`, `.pill`, `.hudcard`, …) are theme-agnostic,
so the live telemetry keeps working untouched.

Rebuild + flash after editing (`idf.py build flash`); the assets are embedded
in the firmware image.

The previews below are **rendered from the real page** — `index.html` loaded headless with
its WebSocket stubbed and one sample telemetry frame pushed through its own render functions
(Dashboard + Configuration, sample data, no kart attached). Regenerate them after any UI
change with:

```
. .venv-schem/bin/activate && python doc/webui/render_previews.py
```

([`render_previews.py`](render_previews.py) — it reads the CSS blocks below, so the skins in
this document and the images cannot drift apart. The few emoji of the real page are swapped
for plain glyphs because the rendering box has no emoji font.) Previews built by hand are how
these three spent a month showing a kart whose caster was still at the rear.

---

## Tactical / mil-spec  — *currently active*

Amber-on-black instrument panel: faint grid overlay, all-sharp corners,
uppercase mono headers, olive-green readouts, amber controls.

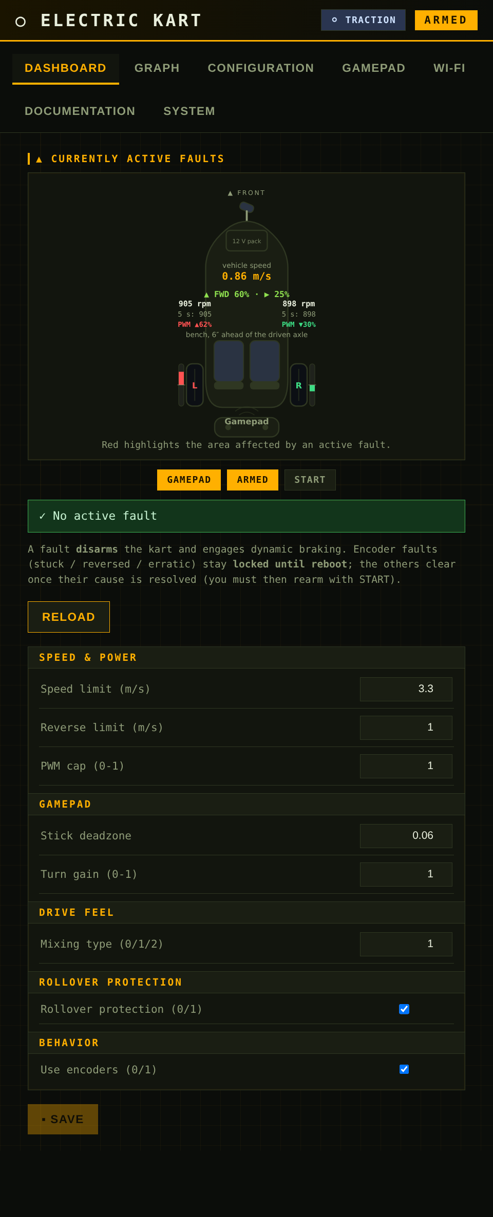
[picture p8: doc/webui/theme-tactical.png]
Tactical theme


```css
:root{
 --bg:#0b0d0a; --card:#12150e; --card2:#1a1e13; --line:#2f3722;
 --txt:#e9efdd; --muted:#8f9c78; --accent:#ffb000; --green:#8fe04f;
 --amber:#ffb000; --red:#ff5a3c;
}
body{font-family:ui-monospace,Menlo,Consolas,monospace;background:
 repeating-linear-gradient(0deg,rgba(255,176,0,.045) 0 1px,transparent 1px 26px),
 repeating-linear-gradient(90deg,rgba(255,176,0,.045) 0 1px,transparent 1px 26px),#0b0d0a}
*{border-radius:0 !important}
header{background:linear-gradient(90deg,#1a1400,#0b0d0a);border-bottom:2px solid var(--accent);
 text-transform:uppercase;letter-spacing:3px}
.hdr-state.s2{background:var(--accent);color:#1a1200}
.pill.brakemode.bm2{background:var(--card2);color:var(--accent);border:1px solid var(--accent)}
.tab{text-transform:uppercase;letter-spacing:1px}
.tab.active{border-bottom-color:var(--accent);color:var(--accent)}
.chart-title{text-transform:uppercase;letter-spacing:2px;color:var(--accent);
 border-left:3px solid var(--accent);padding-left:8px}
.cfgcat{color:var(--accent);text-transform:uppercase;letter-spacing:2px}
.hudcard,form,.status,#bars,.stopok{box-shadow:inset 0 0 0 1px rgba(255,176,0,.06)}
.pill{text-transform:uppercase;letter-spacing:1px}
.pill.on{background:var(--accent);color:#1a1200}
button{background:var(--accent);color:#1a1200;text-transform:uppercase;letter-spacing:1px}
button.alt{background:var(--card2);color:var(--accent);border:1px solid var(--accent)}
#kartdiag .fdms{fill:var(--accent);font:800 16px ui-monospace,monospace}
#kartdiag .fdmix{fill:var(--green)}
```

---

## Racing HUD

Red/carbon motorsport look: diagonal carbon-weave background, checkered strip
under the header, italic uppercase headers, **clipped-corner panels**, a glowing
red speed readout.

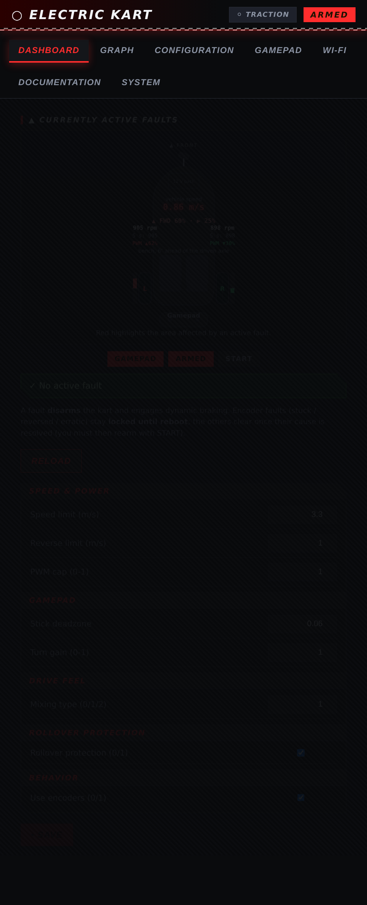
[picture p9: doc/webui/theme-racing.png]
Racing HUD theme


```css
:root{--bg:#0a0b0d;--card:#14161a;--card2:#1c1f26;--line:#2a2e37;--txt:#f2f4f8;
 --muted:#8b93a3;--accent:#ff2d2d;--green:#39d98a;--amber:#ffb020;--red:#ff2d2d;}
body{font-family:'Segoe UI',Roboto,system-ui,sans-serif;background:
 repeating-linear-gradient(45deg,#0b0c0f 0 3px,#08090b 3px 6px),
 repeating-linear-gradient(-45deg,rgba(255,255,255,.015) 0 3px,transparent 3px 6px),#0a0b0d}
header{position:relative;background:linear-gradient(90deg,#2a0000,#0a0b0d 60%);
 border-bottom:2px solid var(--accent);text-transform:uppercase;letter-spacing:2px;
 font-style:italic;box-shadow:0 2px 18px rgba(255,45,45,.25)}
header::after{content:"";position:absolute;left:0;right:0;bottom:-2px;height:5px;
 background:repeating-conic-gradient(#e8e8e8 0 25%,#000 0 50%) 0/14px 14px;opacity:.55}
.tabs{text-transform:uppercase;letter-spacing:1px}
.tab.active{border-bottom-color:var(--accent);background:var(--card);box-shadow:0 3px 14px rgba(255,45,45,.3)}
.chart-title{text-transform:uppercase;letter-spacing:2px;font-style:italic;font-weight:800;
 color:var(--txt);border-left:4px solid var(--accent);padding-left:10px}
.cfgcat{color:var(--accent);text-transform:uppercase;letter-spacing:1.5px;font-style:italic}
.hudcard{background:linear-gradient(180deg,#15171c,#101216);border:1px solid #33383f}
.hudcard,form,.status,#bars,.stopok{
 clip-path:polygon(0 0,calc(100% - 16px) 0,100% 16px,100% 100%,16px 100%,0 calc(100% - 16px))}
.pill{border-radius:4px;text-transform:uppercase;letter-spacing:1px}
.hdr-state{border-radius:4px}
button{border-radius:4px;text-transform:uppercase;letter-spacing:1px;font-style:italic}
input{border-radius:3px}
#kartdiag .fdms{fill:#ff5a5a;font:800 18px ui-monospace,monospace;filter:drop-shadow(0 0 5px rgba(255,45,45,.9))}
#kartdiag .fdmix{fill:#ff9a9a}
```

---

## Cyberpunk neon

Cyan/magenta glow on near-black, subtle scanline overlay, neon-outlined cards
and pills, full mono type, the vehicle body outlined in neon.

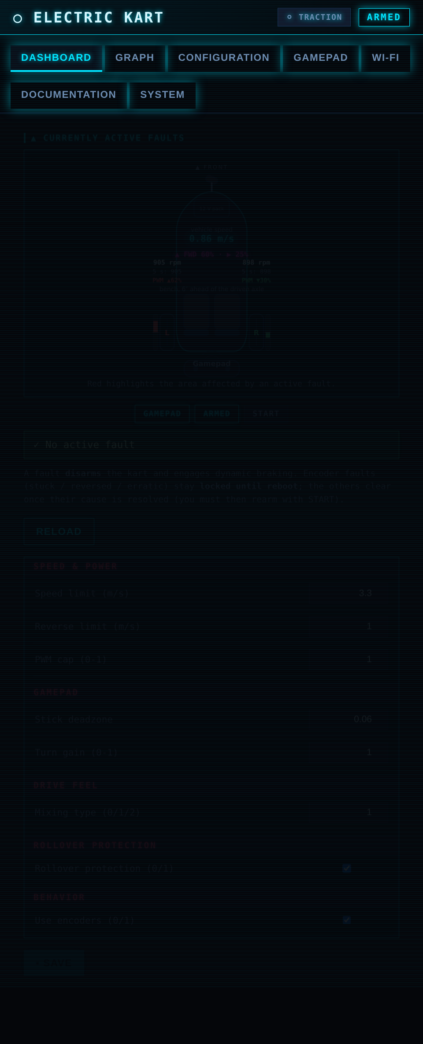
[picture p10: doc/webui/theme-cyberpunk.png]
Cyberpunk neon theme


```css
:root{--bg:#05060a;--card:#0a0e18;--card2:#0f1626;--line:#173154;--txt:#d7f7ff;
 --muted:#6f8bb0;--accent:#00e5ff;--green:#39ffb0;--amber:#ffcf3a;--red:#ff3d6e;}
body{font-family:ui-monospace,Menlo,Consolas,monospace;background:#05060a}
body::before{content:"";position:fixed;inset:0;pointer-events:none;z-index:999;
 background:repeating-linear-gradient(0deg,rgba(0,229,255,.045) 0 1px,transparent 1px 3px)}
header{background:linear-gradient(90deg,#04141c,#05060a);border-bottom:1px solid var(--accent);
 text-shadow:0 0 8px rgba(0,229,255,.8);letter-spacing:2px;box-shadow:0 0 26px rgba(0,229,255,.22)}
.tab.active{border-bottom-color:var(--accent);background:var(--card);color:var(--accent);
 text-shadow:0 0 8px rgba(0,229,255,.7)}
.chart-title{color:var(--accent);text-shadow:0 0 6px rgba(0,229,255,.6);letter-spacing:1.5px}
.cfgcat{color:var(--red);text-shadow:0 0 6px rgba(255,61,110,.6);background:#0f1626}
.hudcard,form,.status,#bars,.stopok{border:1px solid var(--accent);
 box-shadow:0 0 14px rgba(0,229,255,.12),inset 0 0 14px rgba(0,229,255,.05)}
.stopok{border-color:var(--green);box-shadow:0 0 14px rgba(57,255,176,.2)}
.pill.on{background:transparent;color:var(--accent);border:1px solid var(--accent);
 box-shadow:0 0 10px rgba(0,229,255,.5);text-shadow:0 0 6px rgba(0,229,255,.7)}
.hdr-state.s2{background:transparent;color:var(--accent);border:1px solid var(--accent);
 box-shadow:0 0 12px rgba(0,229,255,.6)}
.pill.brakemode.bm2{background:transparent;color:var(--green);border:1px solid var(--green);
 box-shadow:0 0 10px rgba(57,255,176,.4)}
button{background:var(--accent);color:#04121a;box-shadow:0 0 16px rgba(0,229,255,.5)}
button.alt{background:transparent;color:var(--accent);border:1px solid var(--accent);
 box-shadow:0 0 10px rgba(0,229,255,.3)}
input:focus{border-color:var(--accent);box-shadow:0 0 8px rgba(0,229,255,.5)}
#kartdiag .fdms{fill:#00e5ff;font:800 17px ui-monospace,monospace;filter:drop-shadow(0 0 7px rgba(0,229,255,1))}
#kartdiag .fdmix{fill:#ff2bd6;filter:drop-shadow(0 0 4px rgba(255,43,214,.8))}
#kartdiag .body{stroke:var(--accent);stroke-opacity:.55}
```

---
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

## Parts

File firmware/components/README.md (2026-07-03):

# Composants vendorés (Bluepad32 / BTstack) — patchés pour ESP-IDF 6.1

Ces composants sont **volontairement commités** (vendorés) : ils ne viennent pas du registre
de composants ESP-IDF et ont été **patchés à la main** pour compiler sur IDF 6.1. Un clone
frais du dépôt doit compiler sans étape manuelle — ne pas les re-gitignorer.

## Provenance

- `bluepad32/` + `btstack/` : dépôt Bluepad32 (+ BTstack via son submodule), intégrés par
  le script `integrate_btstack.py` de Bluepad32, puis copiés ici.
- `cmd_nvs/`, `cmd_system/` : composants console fournis avec Bluepad32.

## Patches appliqués pour IDF 6.1 (composant `driver` scindé en `esp_driver_*`)

| Fichier | Modification |
|---|---|
| `btstack/CMakeLists.txt` | `priv_requires` += `esp_driver_gpio/uart/i2c/i2s` |
| `cmd_system/CMakeLists.txt` | `REQUIRES` += `esp_driver_uart` |
| `bluepad32/CMakeLists.txt` | retrait de `uni_mouse_quadrature.c` (dépend de `driver/timer.h`, API legacy supprimée) et des plateformes intégrées (nina/unijoysticle/mightymiggy — inutiles avec la plateforme CUSTOM) ; `requires` += `esp_driver_gpio esp_driver_ledc` |
| `bluepad32/uni_mouse_quadrature_stub.c` | **ajouté** : stub du facteur d'échelle souris (référencé par la console BT) |

En cas de montée de version de Bluepad32 : réappliquer ces patches (ou vérifier qu'ils ne
sont plus nécessaires), puis recompiler `firmware/`.

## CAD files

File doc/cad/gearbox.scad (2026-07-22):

// gearbox.scad — Kart 1:17 gearbox, PARAMETRIC (OpenSCAD, standalone — involute
// tooth generator included). Dims = doc/reducteur.md (revision 1:13.33): 24 DP / 20°,
// 16T (motor, metal) → 80T thk 10, then 30T thk 20–25 (compound pinion) → 80T output.
// Center distances 50.80 / 58.21 mm; pulleys 25T→32T (1.28:1) → total 1:17.07. Bearings 6805 (25×37×7), journals Ø24.9, pilot Ø10,
// 3× M4 screws on Ø22. Housing: rear plate (motor) + removable front plate.
//
// Usage: set `part` then F6/export the STL.
//   part = "assembly" (view), "compound" (80T+30T), "output" (80T output),
//          "back" / "front" (plates), "pinion_test" (16T test pinion)
// `explode` spreads the parts apart in the assembly view.

part = "assembly";
explode = 0;            // mm of vertical spacing (assembly view) — 0 = real stack-up

// ───────────────────────── Tooth parameters ─────────────────────────
DP   = 24;              // diametral pitch (imperial)
PA   = 20;              // pressure angle (deg)
BKL  = 0.10;            // linear backlash (mm) — print clearance
mmod = 25.4 / DP;       // equivalent module (1.058 mm)

// ───────────────────────── Mechanical dimensions (mm) ─────────────────────────
T64_1   = 10;           // stage-1 80T thickness
T32     = 20;           // 30T pinion thickness
T64_OUT = 20;           // output 80T thickness (25 recommended, see doc)
GAP     = 1.5;          // axial clearance output 80T ↔ stage-1 80T

JRN_D   = 24.9;         // journal Ø (light fit in the 6805 inner race)
BRG_D   = 37.1;         // bearing seat Ø (6805 = 37.0 + printed fit)
BRG_T   = 7;            // 6805 bearing thickness
PILOT_D = 10;           // central pilot Ø (flange alignment)
BC_D    = 22;           // Ø of the 3-screw bolt circle
SCR_D   = 4.2;          // M4 screw clearance Ø

PLATE_T = 8;            // housing plate thickness
CLR     = 1.0;          // axial clearance part ↔ plate

E1 = (16 + 80) / (2 * DP) * 25.4;   // 50.80 — center distance 16T→80T
E2 = (30 + 80) / (2 * DP) * 25.4;   // 58.21 — center distance 30T→80T

$fn = 90;

// ───────────────────── Gear generator (involute) ─────────────────────
function _rp(z)  = mmod * z / 2;                 // pitch radius
function _rb(z)  = _rp(z) * cos(PA);             // base radius
function _ra(z)  = _rp(z) + mmod;                // tip radius
function _rr(z)  = _rp(z) - 1.25 * mmod;         // root radius
function _roll(z, r) = let(rb = _rb(z)) sqrt(max(0, (r / rb) * (r / rb) - 1));  // roll angle (rad)
function _inv(u) = u * 180 / PI - atan(u);       // involute function (deg), u in rad
// angular half-thickness of a tooth at radius r (deg), backlash subtracted
function _half(z, r) = 90 / z - (BKL / 2) / _rp(z) * 180 / PI + _inv(_roll(z, _rp(z))) - _inv(_roll(z, r));
function _pol(r, a) = [r * cos(a), r * sin(a)];

module gear2d(z)
{
    rr = _rr(z); ra = _ra(z); rb = _rb(z);
    r0 = max(rr, rb);            // start of the involute profile
    ri = rr - 0.6;               // anchor BELOW the root circle: clean overlap with
                                 // the body → no coplanar faces (z-fighting in F5 preview)
    N  = 14;                     // points per flank
    flank = [for (i = [0:N]) let(r = r0 + (ra - r0) * i / N) _pol(r, -_half(z, r))];
    tooth = concat(
        [_pol(ri, -_half(z, r0))],
        flank,
        [for (i = [0:N]) let(r = ra - (ra - r0) * i / N) _pol(r, _half(z, r))],
        [_pol(ri, _half(z, r0))]
    );
    union()
    {
        circle(r = rr);
        for (k = [0:z-1]) rotate(k * 360 / z) polygon(tooth);
    }
}

module gear(z, th) { linear_extrude(height = th) gear2d(z); }

// ───────────────────── Common drillings (pilot + 3 screws) ─────────────────────
module axial_holes(h)
{
    cylinder(d = PILOT_D, h = h);                                  // central pilot
    for (k = [0:2]) rotate(k * 120) translate([BC_D / 2, 0, 0])
        cylinder(d = SCR_D, h = h);                                // 3× M4 screws
}

// ───────────────────── Parts ─────────────────────
// Compound pinion: rear journal + 80T(10) + 30T + front journal, drilled pilot + 3 screws.
module compound_gear()
{
    jl_b = BRG_T + CLR;                                   // rear journal (in the rear bearing)
    jl_f = GAP + T64_OUT - T32 + CLR + BRG_T;             // front journal (reaches the bottom of the seat)
    difference()
    {
        union()
        {
            translate([0, 0, -jl_b]) cylinder(d = JRN_D, h = jl_b);
            gear(80, T64_1);
            translate([0, 0, T64_1]) gear(30, T32);
            translate([0, 0, T64_1 + T32]) cylinder(d = JRN_D, h = jl_f);
        }
        translate([0, 0, -jl_b - 1]) axial_holes(jl_b + T64_1 + T32 + jl_f + 2);
    }
}

// output 80T: long rear journal (crosses the stage-1 plane) + front journal
// extended through the front plate (output stub → pulley).
module output_gear()
{
    z0   = T64_1 + GAP;                        // lower plane of the gear (at the 30T level)
    jl_b = BRG_T + CLR + z0;                   // up to the rear bearing
    jl_f = BRG_T + CLR + PLATE_T + 12;         // crosses the front plate + 12 mm for the pulley
    difference()
    {
        union()
        {
            translate([0, 0, -BRG_T - CLR]) cylinder(d = JRN_D, h = jl_b);
            translate([0, 0, z0]) gear(80, T64_OUT);
            translate([0, 0, z0 + T64_OUT]) cylinder(d = JRN_D, h = jl_f);
        }
        translate([0, 0, -BRG_T - CLR - 1]) axial_holes(jl_b + T64_OUT + jl_f + 2);
    }
}

// 16T test pinion (validates the 24 DP standard against the motor pinion).
module pinion_test() { difference() { gear(16, 8); translate([0,0,-1]) cylinder(d = 5, h = 10); } }

// ───────────────────── Housing (tub-style architecture) ─────────────────────
// Rear plate extended with a peripheral WALL (closed chamber) + mounting LUGS to the
// chassis at the 4 corners; cover screwed onto the wall, COUNTERBORES over the seats.
PL_W = 192; PL_H = 100;                       // footprint excluding lugs (80T Ø86.8)
WALL_T  = 4;                                  // peripheral wall thickness
EAR_W   = 22; EAR_L = 16;                     // mounting lugs (4×, at the corners)
EAR_HOLE = 5.2;                               // chassis mounting hole Ø (M5)
COVER_SCR = 4.2;                              // cover screw Ø (M4, in the wall)
INNER_H = CLR + T64_1 + GAP + T64_OUT + CLR;  // inner height of the chamber
function plate_off() = [-30, 0];              // motor origin → plate corner (centering)

module plate_outline() { offset(r = 6) offset(delta = -6) square([PL_W, PL_H]); }

// Lugs: 2 per end (corners), protrude in X, one chassis hole each.
module ears2d()
{
    for (sx = [0, 1], sy = [0, 1])
        translate([sx * PL_W + (sx ? 0 : -EAR_L), sy * (PL_H - EAR_W) ])
            offset(r = 5) offset(delta = -5) square([EAR_L + 12, EAR_W]);
}
module ear_holes()
{
    for (sx = [0, 1], sy = [0, 1])
        translate([plate_off()[0] + (sx ? PL_W + EAR_L - 9 : -EAR_L + 9),
                   -PL_H / 2 + sy * (PL_H - EAR_W) + EAR_W / 2, -1])
            cylinder(d = EAR_HOLE, h = INNER_H + 2 * PLATE_T + 2);
}
// Positions of the cover screws + dowels (along the wall axis)
function cover_scr_pos() = [for (t = [[18,0],[PL_W/2,0],[PL_W-18,0],[18,1],[PL_W/2,1],[PL_W-18,1]])
    [plate_off()[0] + t[0], -PL_H / 2 + WALL_T / 2 + t[1] * (PL_H - WALL_T)]];
function dowel_pos() = [[plate_off()[0] + WALL_T / 2 + 4, -PL_H / 2 + WALL_T / 2],
                        [plate_off()[0] + PL_W - WALL_T / 2 - 4, PL_H / 2 - WALL_T / 2]];

module bearing_pocket() { translate([0, 0, PLATE_T - BRG_T]) cylinder(d = BRG_D, h = BRG_T + 1); }

// Rear plate = floor + wall + lugs. Inner face of the floor = z = PLATE_T.
module plate_back()
{
    difference()
    {
        union()
        {
            translate([plate_off()[0], -PL_H / 2, 0])
                linear_extrude(height = PLATE_T) union() { plate_outline(); ears2d(); }
            // peripheral wall (up to the cover plane)
            translate([plate_off()[0], -PL_H / 2, PLATE_T])
                linear_extrude(height = INNER_H)
                    difference() { plate_outline(); offset(delta = -WALL_T) plate_outline(); }
        }
        translate([0, 0, -1]) cylinder(d = 22, h = PLATE_T + 2);          // motor pinion clearance hole
        for (x = [E1, E1 + E2]) translate([x, 0, 0]) bearing_pocket();    // 6805 seats (floor)
        // motor mounting holes (25 mm center distance, adapt to the actual motor)
        for (k = [0:1]) rotate(k * 180) translate([0, 12.5, -1]) cylinder(d = 4.2, h = PLATE_T + 2);
        ear_holes();
        for (q = cover_scr_pos()) translate([q[0], q[1], PLATE_T + INNER_H - 12]) cylinder(d = 3.4, h = 13);  // M4 tapping/insert
        for (q = dowel_pos())     translate([q[0], q[1], PLATE_T + INNER_H - 6])  cylinder(d = 4.05, h = 7);  // dowels
    }
}
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

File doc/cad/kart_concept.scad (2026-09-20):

// kart_concept.scad — CONCEPT visuel du kart : TRICYCLE INVERSÉ (proportions du README).
// 1 roulette 10" folle AVANT au centre · 2 roues 10" motorisées ARRIÈRE (boîte 1:12,5 +
// chaîne #35 25T→32T) · banquette 2 enfants 6″ DEVANT l'essieu moteur · batterie dans le
// museau, au-dessus de la roulette · bois standard : 2×3 (38×64) + contreplaqué 1/2" (12,7).
//
// ⚠️ C'est la disposition qui donne la stabilité : un tricycle bascule sur la ligne qui va
// de sa roue SEULE à l'une des roues APPAIRÉES, donc la demi-voie utile vaut
// (distance CG→roue seule)/empattement. La masse posée SUR l'essieu appairé en gardait 80 %
// (a_tip 0,69 g) ; la première version faisait l'inverse et n'atteignait que 0,39 g.
// ⚠️ 2026-08-10 : la banquette a avancé de 6″ et l'essieu a reculé de 6″ — 12″ d'écart
// entre les passagers et l'essieu sur lequel ils étaient assis. w_eff 332 → 254 mm,
// a_tip 0,69 → 0,53 g, charge sur les roues motrices 79 % → 61 %. À partir de là le
// limiteur logiciel N'EST PLUS une redondance : sans lui la simulation renverse le kart.
// Ne JAMAIS déplacer de masse vers la roulette, et ne pas éloigner davantage la banquette.
//
// Repère : x=0 = pivot de la roulette avant (+x vers l'arrière), z=0 sol.
//
// Rendu de doc/cad/kart_concept.png (vue 3/4 avant-gauche : la roulette AVANT doit rester
// visible, c'est tout l'intérêt de l'image) :
//   openscad -o doc/cad/kart_concept.png --imgsize=1600,1000 --projection=p \
//            --camera=0,0,0,68,0,320,4000 --viewall --autocenter doc/cad/kart_concept.scad

// ── Cotes principales (mm) ──
WHEEL_D = 254;   WHEEL_W = 70;       // roues 10" (motrices ET roulette : un seul type)
TRACK   = 832;                       // voie arrière = largeur plancher + largeur de roue
PLAT_W  = 762;   PLAT_L = 1168;      // plateforme 30" × 46"
DECK_X0 = 150;   DECK_X1 = DECK_X0 + PLAT_L;   // 150 → 1318 (la roulette est 150 mm devant)
SHIFT_6IN = 6 * 25.4;                // le déplacement du 2026-08-10, 6″ de chaque côté
DRIVE_X = 1013 + SHIFT_6IN;          // 1165 — essieu moteur RECULÉ de 6″ (le plancher n'a pas bougé)
CLEAR   = 80;                        // garde au sol sous les cales
RISER   = 102;                       // cales 4" : l'essieu descend de 4" sous la structure
LU_W = 38; LU_H = 64;                // 2×3 sur chant
PLY  = 12.7;                         // contreplaqué 1/2"
SEAT_W = 762;                        // banquette 2 enfants = largeur du plancher

FLOOR_Z   = CLEAR + RISER + LU_H;    // 246 — dessus des longerons = dessous du plancher
FLOOR_TOP = FLOOR_Z + PLY;           // ~259 — surface du plancher
AXLE_Z    = WHEEL_D / 2;             // 127
RAIL_Y    = PLAT_W / 2;              // 381 — face EXTERNE des 2×3 : les roues accotent dessus
CASTER_PLATE = WHEEL_D + 78;         // 332 — sous-face de la platine de la roulette

$fn = 48;

module lumber(l)   cube([l, LU_W, LU_H]);      // 2×3 sur chant, le long de x
module lumber_y(l) cube([LU_W, l, LU_H]);      // le long de y
module ply(x, y)   cube([x, y, PLY]);

module wheel() rotate([90, 0, 0]) cylinder(d = WHEEL_D, h = WHEEL_W, center = true);
module rim()   rotate([90, 0, 0]) cylinder(d = WHEEL_D * 0.55, h = WHEEL_W + 2, center = true);

// ───────────────────────────── Châssis bois ─────────────────────────────
// Les deux 2×3 courent sur TOUTE la longueur et débordent de 150 mm vers l'avant pour
// porter la roulette. Ils sont posés au ras des bords du plancher, côté INTÉRIEUR : les
// roues motrices, glissées dans les encoches du plancher, viennent accoter dessus.
module frame()
{
    color("BurlyWood")
    {
        for (sy = [-1, 1])
            translate([0, sy * RAIL_Y - (sy > 0 ? LU_W : 0), FLOOR_Z - LU_H]) lumber(DECK_X1);
        // traverses : nez (poutre de roulette), avant de baie, milieu, essieu, arrière
        for (x = [0, DECK_X0, 560, DRIVE_X - LU_W / 2, DECK_X1 - LU_W])
            translate([x, -RAIL_Y + LU_W, FLOOR_Z - LU_H]) lumber_y(2 * (RAIL_Y - LU_W));
    }
    // plancher 30"×46" — encoches latérales pour glisser les roues motrices en place
    color("Wheat") difference()
    {
        translate([DECK_X0, -PLAT_W / 2, FLOOR_Z]) ply(PLAT_L, PLAT_W);
        for (sy = [-1, 1])
            translate([DRIVE_X - 150, sy * (PLAT_W / 2 - 55) - 30, FLOOR_Z - 1])
                cube([300, 60, PLY + 2]);
    }
}

// ── Cales d'essieu (4") : l'essieu descend de RISER sous les longerons ──
module axle_group()
{
    color("BurlyWood") for (sy = [-1, 1])
        translate([DRIVE_X - 60, sy * (RAIL_Y - 20) - 20, CLEAR]) cube([120, 40, RISER]);
    color("Silver") translate([DRIVE_X, 0, AXLE_Z]) rotate([90, 0, 0])
        cylinder(d = 12.7, h = 940, center = true);
}

// Batterie moto 12 V (~150×87×105) — DANS LE MUSEAU, au-dessus de la roulette, dans un bac
// de contention. C'est la seule masse qu'on veut à l'avant : elle plaque la roulette au sol
// (~20 % de la charge) sans coûter de marge au renversement, puisqu'elle est à l'extrémité
// opposée du triangle de basculement.
module battery()
{
    bx = DECK_X0 + 25;
    color("BurlyWood") for (sy = [-1, 1])
        translate([bx - 15, sy * 60 - (sy > 0 ? 0 : 12), FLOOR_TOP]) cube([180, 12, 70]);
    translate([bx, -44, FLOOR_TOP])
    {
        color("DimGray") cube([150, 88, 105]);
        color("Black")   translate([0, 0, 105]) cube([150, 88, 6]);
        color("Red")     translate([25, 44, 111]) cylinder(d = 14, h = 12);   // borne +
        color("Silver")  translate([125, 44, 111]) cylinder(d = 14, h = 12);  // borne −
    }
}

// ───────────────────────────── Banquette 2 places ─────────────────────────────
// La banquette a AVANCÉ de 6″ : l'assise n'est plus par-dessus l'essieu moteur mais 6″
// devant. Chaque centimètre supplémentaire vers l'avant est de la marge de renversement
// perdue — c'est déjà 78 mm de w_eff pour ces 6″-là.
module seat()
{
    back_x = DECK_X1 - 12 - SHIFT_6IN;
    color("Peru")
    {
        translate([DECK_X1 - 300 - SHIFT_6IN, -SEAT_W / 2, FLOOR_TOP + 30]) ply(300, SEAT_W);  // assise
        translate([back_x, -SEAT_W / 2, FLOOR_TOP]) rotate([0, -82, 0]) ply(340, SEAT_W); // dossier
    }
    color("BurlyWood") for (sy = [-1, 0, 1])                                             // cales d'assise
        translate([DECK_X1 - 290 - SHIFT_6IN, sy * (SEAT_W / 2 - 40) - 20, FLOOR_TOP]) cube([280, 40, 30]);

    // GARDE-CORPS latéraux (CP 1/2") : empêchent l'enfant de tomber sur les côtés
    color("Peru") for (sy = [-1, 1])
        translate([DECK_X1 - 370 - SHIFT_6IN, sy * (SEAT_W / 2) - (sy > 0 ? PLY : 0), FLOOR_TOP])
            cube([370, PLY, 300]);

    // Arrêt d'urgence : champignon AU SOMMET DU DOSSIER, centré (accessible aux 2 enfants
    // et à un adulte derrière le kart). Il ouvre la BOBINE du relais 40 A.
    top_x = back_x + 340 * cos(82); top_z = FLOOR_TOP + 340 * sin(82);
    color("Peru")   translate([top_x - 45, -50, top_z - 6]) cube([90, 100, 14]);   // platine
    color("Yellow") translate([top_x, 0, top_z + 8]) cylinder(d = 60, h = 6);
    color("Red")    translate([top_x, 0, top_z + 12]) cylinder(d = 45, h = 26);
}

// ────────────────── Propulsion arrière (par côté) : boîte 1:12,5 + chaîne #35 ──────────────────
R32 = 48.6;   // rayon primitif du pignon de roue 32T (#35, pas 9,525)
R25 = 38.0;   // rayon primitif du pignon de sortie de boîte 25T
CDIST = 165;  // entraxe choisi (doc/reducteur.md) — la boîte est DEVANT l'essieu
module drive_side(sy)
{
    color("DimGray")   translate([DRIVE_X, sy * TRACK / 2, AXLE_Z]) wheel();
    color("Gainsboro") translate([DRIVE_X, sy * TRACK / 2, AXLE_Z]) rim();
    // pignon 32T côté intérieur de la roue
    color("Orange") translate([DRIVE_X, sy * (TRACK / 2 - WHEEL_W / 2 - 12), AXLE_Z])
        rotate([90, 0, 0]) cylinder(r = R32, h = 10, center = true);
    // sortie de boîte 25T à CDIST devant, LÉGÈREMENT PLUS HAUT (le mou de la chaîne pend
    // sur le brin, pas dans les dents — voir doc/schematics/chain_layout.png)
    gx = DRIVE_X - CDIST * 0.94;  gz = AXLE_Z + CDIST * 0.34;
    color("Orange") translate([gx, sy * (TRACK / 2 - WHEEL_W / 2 - 12), gz])
        rotate([90, 0, 0]) cylinder(r = R25, h = 10, center = true);
    // brins de chaîne (stylisés)
    color("DarkSlateGray") for (dz = [R32 - 8, -R32 + 8])
        translate([gx, sy * (TRACK / 2 - WHEEL_W / 2 - 12), AXLE_Z + dz])
            rotate([0, 90 - atan2(gz - AXLE_Z, DRIVE_X - gx), 0]) cube([6, 6, CDIST], center = true);
    // carter imprimé + moteur
    color("SlateGray") translate([gx - 90, sy * (RAIL_Y - 60) - 20, gz - 85]) cube([180, 40, 170]);
    color("DarkGray")  translate([gx + 90, sy * (RAIL_Y - 60), gz]) rotate([0, 90, 0])
        cylinder(d = 42, h = 80);
}
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

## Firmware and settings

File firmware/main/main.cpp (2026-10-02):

// main.cpp — Entry point: initializes the subsystems then starts the control.
// All the motor control is in controller.cpp.
#include "config.hpp"
#include "controller.hpp"
#include "evlog.hpp"
#include "hardware.hpp"
#include "leds.hpp"
#include "mdns_svc.hpp"
#include "webserver.hpp"

#include "esp_log.h"
#include "esp_ota_ops.h"
#include "nvs_flash.h"

extern "C" void app_main()
{
    board::motorsIdleEarly();  // FIRST: motor pins at rest (avoids any jolt at boot)

    const esp_err_t nv = nvs_flash_init();
    if (ESP_ERR_NVS_NO_FREE_PAGES == nv || ESP_ERR_NVS_NEW_VERSION_FOUND == nv)
    {
        ESP_ERROR_CHECK(nvs_flash_erase());
        ESP_ERROR_CHECK(nvs_flash_init());
    }

    configInit();        // settings table (NVS)
    evlog::init();       // persistent event log ("why did it disarm") — logs this boot
    wifiSoftAPInit();    // "Kart-Config" access point
    webServerStart();    // HTTP/WebSocket server
    mdnsStart();         // advertises http://kart.local (after the server: the port is open)
    Controller::init();  // hardware (PWM/DIR motor outputs, gamepad)
    ledsStart();         // WS2812B strip display task
    Controller::start(); // 500 Hz control loop (system disarmed at startup)

    // OTA rollback: a freshly uploaded image boots "pending verify". Reaching this line means
    // every subsystem came up without a panic → keep it. (No-op on an already-valid image.)
    // Done HERE, while still disarmed: it writes otadata, and flash writes freeze the loop.
    esp_ota_mark_app_valid_cancel_rollback();

    ESP_LOGI("kart", "Kart ready. Config: Wi-Fi 'Kart-Config' → http://%s.local (or http://192.168.4.1)",
             mdnsHostname());
}

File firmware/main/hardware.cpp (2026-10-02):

// hardware.cpp — Hardware access (differential variant: 2 REAR motors, NO sensor at all).
// No inputs of any kind: arming is a gamepad button and power is a physical switch.
// The driver handles (LEDC) live here as statics; the rest of the firmware goes through the
// free functions of the `board` namespace. (The two AS5600 encoders and their I2C buses
// were removed on 2026-09-29, with everything that used them.)
#include "hardware.hpp"

#include <atomic>
#include "soc/dport_reg.h"

#include <cmath>

#include "config.hpp"
#include "pinout.hpp"

#include "driver/gpio.h"
#include "driver/ledc.h"
#include "esp_log.h"

static const char* TAG = "board";

// Rotation direction (level applied to the driver's DIR pin).
enum class Dir : int { Forward = 1, Reverse = 0 };

static inline float clampf(float v, float lo, float hi)
{
    return v < lo ? lo : (v > hi ? hi : v);
}

namespace
{
// LEDC timer resolution (esp_driver_ledc type) — the corresponding numeric value
// (PWM_MAX = 4095) lives in control_types.hpp, the only one useful to the logic.
constexpr ledc_timer_bit_t PWM_RES = LEDC_TIMER_12_BIT;


// LEDC clock SENTINEL — diagnostic + auto-repair of the suspected race:
// recurring "Interrupt WDT" crash with the PC frozen on a LEDC register WRITE, under
// radio load (Wi-Fi/BT). Hypothesis: a concurrent read-modify-write (unlocked on the
// radio blob side) on DPORT_PERIP_CLK_EN_REG loses the LEDC clock bit; and writing to a
// peripheral WITHOUT a clock freezes the APB bus on ESP32 → interrupt watchdog with no dump.
// We check the bit BEFORE each motor write: gated off → repaired + counted (System page).
std::atomic<uint32_t> m_ledc_clk_fix{0};

inline void ledcClockGuard()
{
    if (0 == (DPORT_REG_READ(DPORT_PERIP_CLK_EN_REG) & DPORT_LEDC_CLK_EN))
    {
        DPORT_REG_SET_BIT(DPORT_PERIP_CLK_EN_REG, DPORT_LEDC_CLK_EN);
        DPORT_REG_CLR_BIT(DPORT_PERIP_RST_EN_REG, DPORT_LEDC_RST);
        const uint32_t n = m_ledc_clk_fix.fetch_add(1) + 1;
        ESP_LOGE(TAG, "LEDC clock found GATED OFF (DPORT/radio race?) — repaired (n=%lu)",
                 static_cast<unsigned long>(n));
    }
}

// Output state caches: we write LEDC/GPIO ONLY if the value changes. At 500 Hz in
// permanent braking, this eliminates ~2000 useless APB writes/s (and shrinks by the same
// amount the exposure window to the clock race above).
uint32_t m_duty_last[2] = {UINT32_MAX, UINT32_MAX};
int      m_dir_last[2]  = {-1, -1};

void dirPin(gpio_num_t pin, Dir d)
{
    const int idx = (pins::DIR_L == pin) ? 0 : 1;
    if (m_dir_last[idx] == static_cast<int>(d)) return;
    m_dir_last[idx] = static_cast<int>(d);
    gpio_set_level(pin, static_cast<int>(d));
}

void setDuty(ledc_channel_t ch, uint32_t duty)
{
    const int idx = (LEDC_CHANNEL_0 == ch) ? 0 : 1;
    if (m_duty_last[idx] == duty) return;
    ledcClockGuard();
    m_duty_last[idx] = duty;
    ledc_set_duty(LEDC_LOW_SPEED_MODE, ch, duty);
    ledc_update_duty(LEDC_LOW_SPEED_MODE, ch);
}

void initLED()
{
    gpio_config_t io{};
    io.pin_bit_mask = (1ULL << pins::LED);
    io.mode = GPIO_MODE_OUTPUT;
    gpio_config(&io);
}

void initMotors()
{
    ledc_timer_config_t timer{};
    timer.speed_mode = LEDC_LOW_SPEED_MODE;
    timer.duty_resolution = PWM_RES;
    timer.timer_num = LEDC_TIMER_0;
    timer.freq_hz = hw::PWM_FREQ_HZ;
    timer.clk_cfg = LEDC_AUTO_CLK;
    ESP_ERROR_CHECK(ledc_timer_config(&timer));

    auto configChannel = [](ledc_channel_t ch, gpio_num_t pin)
    {
        ledc_channel_config_t c{};
        c.gpio_num = pin;
        c.speed_mode = LEDC_LOW_SPEED_MODE;
        c.channel = ch;
        c.timer_sel = LEDC_TIMER_0;
        c.duty = 0;
        c.hpoint = 0;
        ESP_ERROR_CHECK(ledc_channel_config(&c));
    };
    configChannel(LEDC_CHANNEL_0, pins::PWM_L);
    configChannel(LEDC_CHANNEL_1, pins::PWM_R);

    gpio_config_t io{};
    io.pin_bit_mask = (1ULL << pins::DIR_L) | (1ULL << pins::DIR_R);
    io.mode = GPIO_MODE_OUTPUT;
    io.pull_down_en = GPIO_PULLDOWN_ENABLE;
    gpio_config(&io);
    // The LEDC attach reconfigures the PWM pins: re-arm their internal pull-downs.
    gpio_pulldown_en(pins::PWM_L);
    gpio_pulldown_en(pins::PWM_R);
    dirPin(pins::DIR_L, Dir::Forward);
    dirPin(pins::DIR_R, Dir::Forward);
    board::motorsBrake();   // default state: dynamic braking (never coasting)
}

void motorApply(ledc_channel_t ch, gpio_num_t dir, float v, uint32_t cap)
{
    dirPin(dir, (v >= 0) ? Dir::Forward : Dir::Reverse);
    setDuty(ch, static_cast<uint32_t>(fabsf(clampf(v, -1.f, 1.f)) * cap));
}
} // namespace

// ───────────────────────────── Public API ─────────────────────────────
void board::init()
{
    initLED();
    initMotors();
    board::led(false);
}

void board::led(bool on)
{
    gpio_set_level(pins::LED, on ? 1 : 0);
}

void board::motorsSet(float l, float r, uint32_t cap)
{
    motorApply(LEDC_CHANNEL_0, pins::DIR_L, l, cap);
    motorApply(LEDC_CHANNEL_1, pins::DIR_R, r, cap);
}
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

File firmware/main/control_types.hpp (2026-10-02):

// control_types.hpp — PURE control types and constants (compilable on the host).
// Extracted from config.hpp so the control logic (controller_core) and the simulator
// (test_host/sim) share the SAME source of truth: KartConfig, the state/stop enums
// and hw:: constants — without any ESP-IDF dependency.
#pragma once

#include <cstddef>
#include <cstdint>

// Round a float to the nearest int (half away from zero).
inline int iround(float v)
{
    return static_cast<int>(v < 0 ? v - 0.5f : v + 0.5f);
}

// ───────────────────────── Hardware constants (compile-time) ─────────────────────────
namespace hw
{
constexpr int   CTRL_HZ       = 500;   // control loop (FreeRTOS tick 1000 Hz)
constexpr int   CTRL_DT_MS    = 1000 / CTRL_HZ;
constexpr float CTRL_DT_S     = 1.0f / CTRL_HZ;
constexpr int   WDT_TIMEOUT_S = 2;   // mirror of sdkconfig's CONFIG_ESP_TASK_WDT_TIMEOUT_S
                                     // (the sdkconfig value is what actually arms it, with
                                     // PANIC=y: a stalled control loop reboots, not warns)

constexpr int PWM_FREQ_HZ = 18000;
constexpr int PWM_MAX     = 4095;   // 12 bits (the LEDC resolution lives in hardware.cpp)

// Motors nominally 12 V, driver 6–30 V. The pack is ALWAYS 12 V (design input, see
// doc/electronique.md): nothing measures the voltage any more, so the only PWM ceiling
// is the manual one (KartConfig::duty_cap_frac). The old automatic cap 12 V / measured
// Vbat, the LVC and their smoothing constants went with the ADS1115.

// Protobuf reply arena (webserver.cpp). Declared HERE, not there, so config_params.cpp —
// the file that grows every time a parameter is added — can static_assert against it and
// FAIL THE BUILD instead of failing the socket. It has bitten once: four params with long
// help text pushed the config past the old 6144 and the page just lost its connection.
// Sized to the guard, not the other way around: this is permanent BSS and every static
// kilobyte comes straight out of the heap pool (RAM audit 2026-07-31), so keep it snug —
// but when the compile-time worst-case guard in config_params.cpp fires on a new param,
// prefer growing this over butchering help texts (they are the kart's manual) — the guard
// recomputes the exact worst-case bound at every build, so the number never rots here.
constexpr size_t PB_REPLY_CAP = 9216;

// Arming and haptic feedback (named — no magic numbers in the controller).
constexpr float ARM_CENTER_MAX   = 0.08f;    // stick considered "centered" to arm
constexpr float PUSH_MIN         = 0.5f;     // stick considered "pushed" (rumble if blocked)
constexpr int64_t RUMBLE_BLOCK_INTERVAL_US = 800000;   // repetition of the "blocked" rumble
// No sensor of any kind on the wheels (2026-09-29): no encoders, so no speed limiter, no
// PID braking and no rollover protection. The kart is stick → PWM, bounded by duty_cap only.

// Gamepad heartbeat: gamepads stream their HID reports continuously (~10-20 ms).
// Link "connected" but silent past this = communication lost → disarm + braking (the
// Bluetooth supervision timeout, by contrast, takes several seconds). 750 ms, raised from
// 250 ms after real-world driving: Wi-Fi/BT share the one radio, and coexistence can starve
// the HID stream for a few hundred ms — long enough to false-trip the old bound mid-run.
// At ~2.5 m/s top speed (18T→32T chain), 750 ms is ~1.9 m of travel before the brake, versus several
// seconds if we waited for the BT supervision timeout.
constexpr int64_t PAD_HB_TIMEOUT_US  = 750000;
} // namespace hw

// ───────────────────────── Configuration (named fields, persisted) ─────────────────────────
// Named, persisted settings. Each field is a float, or an int32 for integer/bool params
// (accessed through the typed CfgVal/CfgField union — see cfgGet/cfgSet in config_params.cpp).
struct KartConfig
{
    float   duty_cap_frac;  // PWM ceiling (0..1) — the ONLY speed limit
    float   thr_deadzone;   // stick deadzone (forward AND turn)
    float   turn_gain;      // share of the differential at full X stick (0..1)
    int32_t mix_type;       // stick→motor mixing: 0 linear, 1 expo (mixer.hpp)
    float   mix_expo_fwd;   // expo strength on the throttle axis (0 = linear, 1 = cubic)
    float   mix_expo_turn;  // expo strength on the steering axis
    int32_t accel_pct_s;    // how fast the PWM may RISE, % of full duty per second (0 = off)
    int32_t decel_pct_s;    // how fast it may FALL back to 0 — this IS the pseudo-freewheel
    int32_t mot_inv_l;      // 1 = flip the LEFT motor output (convention: +PWM = forward)
    int32_t mot_inv_r;      // 1 = flip the RIGHT motor output
    int32_t mot_swap_lr;    // 1 = LEFT wheel on driver channel R and vice versa (crossed wiring)
    int32_t arm_hold_ms;
    int32_t disarm_s;
    int32_t led_count;
    int32_t led_brightness;

    void setDefaults();
    void clampAll();
};

enum class PType : uint8_t { Float, Int, Bool };

// A 4-byte config scalar: a float, OR an int32 (bools are stored as 0/1 int32). Tagged by
// PType — only ever read/write the member matching the type (see cfgGet/cfgSet).
union CfgVal   { float f; int32_t i; };
union CfgField { float KartConfig::* f; int32_t KartConfig::* i; };

struct ParamDesc
{
    const char* name;   // NVS key + JSON key (≤ 15 characters for NVS)
    const char* desc;   // short label for the web page
    const char* cat;    // category (visual grouping in the config page)
    const char* help;   // long description (tooltip on field hover)
    PType       type;
    CfgVal      min, def, max;   // .f for Float, .i for Int/Bool
    CfgField    field;           // member pointer to the target field (member matching `type`)
};

extern const ParamDesc PARAMS[];
extern const int       PARAM_COUNT;

// Typed access to a parameter, widened to / narrowed from float — the config wire
// (protobuf ParamVal/ParamMeta) stays float; only the internal storage is typed.
float cfgGet(const KartConfig& c, const ParamDesc& p);
void  cfgSet(KartConfig& c, const ParamDesc& p, float v);
float cfgMin(const ParamDesc& p);
float cfgMax(const ParamDesc& p);
float cfgDef(const ParamDesc& p);

// ───────────────────────── Telemetry ─────────────────────────
// 3 (Fault) is RETIRED, not reused: there is no fault state any more (see Stop below).
enum class State : int { Lockout = 0, Calibrate = 1, Run = 2 };
// EFFECTIVE output mode (displayed permanently on the web page), live only — never stored:
// None = driving (A held + stick) · Dynamic = phase short-circuit (A released, disarmed,
// blocked) · Coast = PSEUDO-freewheel (A held, stick centered: the PWM slides down at decel_pct_s).
enum class BrakeMode : int { None = 0, Dynamic = 1, Coast = 2 };
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

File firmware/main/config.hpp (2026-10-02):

// config.hpp — ESP-side configuration: PARAMS table (NVS/web key → field), persistence,
// shared telemetry (KartStatus, atomics) and thread-safe access. The pure control TYPES
// (KartConfig, enums, hw:: constants) live in control_types.hpp (shared with the host).
#pragma once

#include <cstdint>
#include "freertos/FreeRTOS.h"
#include "freertos/semphr.h"

#include "control_types.hpp"

struct KartStatus
{
    // SIMPLE struct (no more atomics): read by COPY under mutex via statusSnapshot(),
    // written by statusPublish() — a single writer (the control loop).
    int      m_state = static_cast<int>(State::Lockout);
    int      m_stop = static_cast<int>(Stop::None);   // why it will not drive (one cause)
    float    m_fwd = 0.f;     // forward command after the deadzone [-1..1]
    float    m_turn = 0.f;    // turn command after the deadzone [-1..1]
    bool     m_btn_start = false;
    bool     m_btn_drive = false;   // A held (hold to drive)
    float    m_out_l = 0.f;   // left motor PWM [-1..1]
    float    m_out_r = 0.f;
    int      m_brake_mode = static_cast<int>(BrakeMode::Dynamic);
    bool     m_arming = false;
    bool     m_estop = false;
    bool     m_pad_conn = false;
    int      m_pad_batt = -1;   // gamepad battery 0..100 (-1 unknown)
    float    m_pad_x = 0.f;     // RAW turn stick [-1..1] (physical position, circle)
    float    m_pad_y = 0.f;
    float    m_pad_cx = 0.f;    // COMPENSATED turn command circle→square [-1..1]
    float    m_pad_cy = 0.f;
    float    m_pad_zl = 0.f;    // analog triggers [0..1] (display)
    float    m_pad_zr = 0.f;
    float    m_pad_rx2 = 0.f;   // RIGHT stick [-1..1] (display only)
    float    m_pad_ry2 = 0.f;
    unsigned m_pad_btns = 0;    // mask: buttons | (misc<<16) | (dpad<<24) (display)
};

// PROTECTED access to the telemetry (internal mutex): coherent copy for the readers
// (webserver, LED), atomic write of a block for the control loop.
KartStatus statusSnapshot();
bool       statusTrySnapshot(KartStatus& out);   // timeout 0 — for the esp_timer callbacks
void       statusPublish(const KartStatus& s);

// ───────────────────────── Globals ─────────────────────────
extern KartConfig        g_cfg;
extern SemaphoreHandle_t g_cfg_mtx;

void       configInit();
bool       configLoad();
bool       configSave();
KartConfig configSnapshot();
void       configUpdate(const KartConfig& c, bool persist);   // caller must refuse while armed

bool configGetWifi(char* ssid, size_t ssid_size, char* pass, size_t pass_size, bool* enabled = nullptr);
void configSetWifi(const char* ssid, const char* pass, bool enabled);

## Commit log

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2026-06-07 firmware: cœur de contrôle ESP-IDF 6.1 (C++)
    Boucle d'asservissement 500 Hz (FreeRTOS 1000 Hz) : accélérateur = PWM direct,
    frein PID vers vitesse 0, limiteur de vitesse par PID, vitesse mesurée par AS5600
    (I2C, angle 12 bits absolu, dérivation + wrap). Machine à états, armement, LVC anti-sag,
    watchdog, latch d'alimentation (POWER_HOLD). Config par table PARAMS (pointeur-vers-membre, NVS).
    [config.hpp, hardware.cpp, main.cpp]
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2026-06-08 Applique le coding-style partout : const-correctness, Allman, Yoda
    - Const : ~40 variables locales jamais réassignées passées en const
    (controller, hardware, pid, ringbuffer, webserver, config, leds, main)
    - Allman : accolades ouvrantes mises sur leur propre ligne (iround, namespace NVS,
    Ws2812::setBrightness/count, board::btnStart/btnReverse, angleDelta if)
    - Yoda : controller 'cfg.allow_reverse != 0.f' -> '0.f != cfg.allow_reverse'
    - Retrait de la fonction morte readBody() (webserver)
    - Préfixes m_ des variables statiques de fichier conservés (convention projet établie)
    Build OK (sans avertissement), flashé.
    [config.hpp, hardware.cpp, main.cpp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]
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2026-07-15 Modèle OpenSCAD paramétrique du réducteur 1:8
    doc/cad/gearbox.scad — autonome (générateur de denture en développante
    inclus, aucune bibliothèque) :
    - Denture 24 DP / 20° / backlash 0,1 mm ; entraxes calculés (42,33 / 50,80).
    - Pièces : pignon composé 64T(10)+32T(20) avec tourillons Ø24,9, pilote Ø10
    et 3 vis M4 sur Ø22 ; 64T de sortie (20 mm) avec tourillon de sortie
    traversant ; plaques arrière (moteur) / avant dévissable avec logements
    6805 (Ø37,1×7), pions de centrage et vis de coin ; pignon d'essai 16T.
    - Sélecteur `part` pour exporter chaque STL, vue `assembly` avec `explode`.
    - Les 5 pièces validées à l'export STL (rendu CGAL sans erreur) ; phases
    d'engr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
    [gearbox.scad]
2026-07-15 OpenSCAD : couvercle translucide + fix des artefacts d'affichage
    Deux causes aux surfaces « bizarres » de l'aperçu (F5/OpenCSG) :
    - dents exactement tangentes au cercle de pied → faces coplanaires
    (z-fighting) : les dents sont maintenant ancrées 0,6 mm SOUS le cercle
    de pied (chevauchement franc) ;
    - transparence mal triée en profondeur par l'aperçu : le couvercle
    translucide est déclaré en DERNIER (fondu correct par-dessus le reste).
    Couvercle avant en lightsteelblue alpha 0,30. NB : le rendu complet
    (F6/CGAL) de la 2021.01 perd les couleurs → l'image de doc est générée
    en aperçu. Tourillon avant du pignon composé rallongé jusqu'au fond du
    logement (l'empilement tena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
    [gearbox.scad]
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2026-07-16 Plafond PWM automatique 12 V / Vbat mesurée (batterie 12-24 V au choix)
    Le driver accepte 6-30 V : plutôt qu'un bridage PWM fixe pensé pour un pack
    20 V, le firmware plafonne le duty à MOTOR_V_NOM/Vbat (ctl::dutyCapVolts,
    testée sur hôte) — batterie moto 12 V → ~100 %, pack 20 V → ~60 %, 24 V →
    ~50 %. Vbat lissée lentement (τ≈1 s) pour que l'affaissement sous charge ne
    fasse pas osciller le plafond ; capteur absent → pas de plafond auto (le
    manuel reste). Clé duty_cap_frac renommée duty_cap (défaut 1,0 = laisser
    faire l'auto) ; plages des seuils LVC élargies 8-29 V (12 V moto / 20 V
    outil / 24 V série — pont diviseur à dimensionner en conséquence, tableau
    dans le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
    [config.hpp, control_math.hpp]
2026-07-16 Détection batterie 12/24 V au démarrage + config web par catégories
    - ctl::BattDetect (testée sur hôte) : tension stable 3 s (écart ≤ 0,5 V)
    puis classement 12 V ou 24 V (seuil 18 V — une 12 V en charge reste
    ≤ ~14,8 V, une 24 V vide reste ≥ ~21 V). Type FIGÉ jusqu'au redémarrage :
    on ne change jamais de batterie système allumé.
    - Seuils LVC/avertissement codés en dur par type (plomb) : 12 V →
    11,5/10,5/12,0 ; 24 V → 23,0/21,0/24,0. Les paramètres vbat_warn_v,
    vbat_cut_v, vbat_recover_v et cell_count disparaissent (liés à la chimie,
    pas au réglage). Type inconnu → pas de LVC (kart désarmé au boot).
    - Télémétrie batt_type (0/12/24) : affiché sur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
    [config.hpp, control_math.hpp, webserver.cpp]
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2026-07-16 Fix reboots watchdog : débordement de pile httpd (+ mix G/D, échelle batterie côté micro)
    CRASH (reboot ~20 s avec 2 clients web) : buildConfigJson posait un
    char buf[640] sur la pile de la tâche httpd (4096 par défaut) ; avec
    vsnprintf/%g par-dessus, la pile débordait, corrompait le tas et gelait
    l'écriture LEDC de la tâche de contrôle → Interrupt WDT (TG1WDT), et le
    périphérique restait coincé au boot suivant (initMotors) jusqu'au reset
    matériel. Bissection 3d6aeeb (sain) → 7f3da52 (fautif), reproduit par soak
    2 clients à 20 Hz, corrigé puis validé : 4 min / 4572 messages / 0 crash.
    - buildConfigJson : textes concaténés dans la std::string (tas), plus
    aucun grand t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
    [config.hpp, control_math.hpp, webserver.cpp]
2026-07-17 Protocole web allégé + défauts « encodeur absent » par roue
    Protocole : l'immuable ne part qu'une fois par connexion — « get » (méta-
    données de config) et « sysinfo » (puce/MAC/version) à l'ouverture ; ensuite
    « vals » (valeurs seules ~0,8 ko au lieu de 6 ko) après save/recharger,
    « sysdyn » (uptime/heap) à l'affichage de l'onglet Système, graphiques
    toutes les 5 s. Le statut (~0,4 ko) reste le seul flux 20 Hz. Soak 2 clients
    2 min (tous types de messages) : 0 crash, manette connectée pendant le test.
    Défauts : présence de chaque AS5600 suivie au niveau I2C (m_enc_present,
    rafraîchie à 500 Hz par les lectures existantes). Avec use_encoders=1, un
    capteur muet est B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
    [config.hpp, hardware.cpp, webserver.cpp]
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2026-07-17 LE bug : épuisement du tas par l'historique (17 ko de JSON par requête)
    Cause racine des « Interrupt WDT » aléatoires (traqués sur 2 jours) :
    buildHistJson produisait ~17 ko à anneaux PLEINS (600+360 points × 7
    séries) ; avec 2 clients simultanés les pics d'allocation vidaient le tas
    (~40 ko libres, heap_min mesuré < 11 ko et en chute) → malloc en échec dans
    les internals radio/lwip → gels en section critique → watchdog
    d'interruption, PC figé sur une écriture LEDC (victime, pas coupable).
    D'où le caractère probabiliste ET la dépendance au temps : boot frais =
    anneaux vides = « stable » — ce qui avait faussé la bissection initiale.
    Correctifs :
    - Historique : mê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
    [hardware.cpp, webserver.cpp]
2026-07-17 Chemin WebSocket 100 % sans allocation dynamique + audit complet
    Prévisibilité mémoire (suite du crash « tas épuisé ») : plus AUCUNE
    std::string dans webserver.cpp — arène statique unique m_reply[8 ko]
    (la tâche httpd est strictement séquentielle : pas de réentrance),
    tampon de réception statique m_body[2 ko], cache d'historique statique
    m_hist_json[3 ko] reconstruit au plus 1×/s, writer borné rPut/rFmt/rEsc,
    parseurs C bornés (jsonNumC/jsonStrC), Ring::appendJsonC sans tas (testé
    sur hôte, y compris la troncature propre). Résultat mesuré : heap_free
    CONSTANT à 27,5 ko sous soak 2 clients 8 min (~9100 messages), 0 crash.
    Dispatch des commandes EXACT sur le champ type (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
    [config.hpp, webserver.cpp]
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2026-07-17 Corrections d'audit : RevDetect, NVS différée/delta, armement, marges, logs
    1. FAUSSE DÉTECTION « encodeur inversé » en freinage au stick (la vraie
    faille) : le test naïf déclenchait sur toute opposition commande/vitesse
    > 400 ms — or décélérer depuis 2-3 m/s au stick oppose bien plus
    longtemps → arrêt total injustifié en pleine conduite. Nouveau
    ctl::RevDetect (testé sur hôte, 4 scénarios) : l'opposition ne confirme
    l'inversion QUE si |v| ne décroît pas (une décélération fond vers zéro,
    un câblage inversé donne une vitesse opposée stable ou croissante).
    2. NVS : écritures DELTA (clé sautée si valeur inchangée — usure et gel de
    cache r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
    [config.hpp, control_math.hpp, webserver.cpp]
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2026-07-18 Scénario pente 8 % au frein dynamique seul + job CI « simulation »
    descente_frein_dynamique : pente 8 %, brk_pid_enable=0 → le court-circuit
    des phases ne peut pas ARRÊTER (sa force est proportionnelle à la vitesse)
    mais PLAFONNE la descente à une vitesse terminale rampante — mesurée à
    0,42 m/s dans le modèle. L'assert documente les deux faits : v finale
    < 0,7 m/s (pas d'emballement, « il tient ») et > 0,05 m/s (il ne s'arrête
    jamais — cohérent avec l'avertissement du README : coupure d'alimentation
    = roue libre, et frein dynamique = frein de vitesse, pas de stationnement).
    CI : la simulation devient un job dédié et VISIBLE (« simulation ») via
    test_host/run_sim.sh, p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
    [scenarios.hpp, sim_main.cpp]
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2026-07-18 Dead-man : WDT 2 s en mode panique + frein dynamique par défaut électrique
    - Task watchdog 5 s → 2 s et CONFIG_ESP_TASK_WDT_PANIC=y : sans PANIC le
    WDT n'imprimait qu'un avertissement — une boucle de contrôle gelée
    laissait les moteurs sur leur dernier PWM indéfiniment. Désormais :
    gel → panique → reboot → frein.
    - Broches moteur : tout bas = frein (duty 0 + DIR bas court-circuitent le
    pont). Pull-down internes armés dès motorsIdleEarly() (première ligne
    d'app_main), réarmés après l'attache LEDC ; initMotors se termine en
    frein dynamique (plus jamais en roue libre). POWER_HOLD (actif bas)
    reçoit aussi son pull-down.
    - README : les pull-down internes ne su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
    [hardware.cpp]
2026-07-21 Vitesse : limite de recul distincte (rev_speed_ms) + fin de la bride PWM
    La marche arrière n'est plus bridée par un plafond PWM fixe (rev_limit
    supprimé) mais par le limiteur de vitesse PID, avec sa PROPRE cible :
    - speed_limit_ms : limite en marche AVANT (inchangée) ;
    - rev_speed_ms : limite en marche ARRIÈRE (défaut 1 m/s, la roulette ne
    guide pas en recul → rester lent).
    Cible du PID choisie selon le SENS MESURÉ (v_veh < 0), pas la consigne :
    en plugging (stick arrière alors que le kart avance encore) la cible reste
    celle de l'avant, l'autorité de freinage n'est pas amputée.
    Scénario sim marche_arriere : plein recul convergé sur rev_speed_ms (2 m/s
    de test), avant laiss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
    [config_params.cpp, control_types.hpp, controller_core.cpp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]
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2026-07-25 Encoders: detect magnet out of field (AS5600 STATUS) → Faults page
    The old "encoder present" check was just an I2C ACK, which the AS5600 gives
    whether or not a magnet is in range — so a missing/misaligned magnet passed
    as present and only showed up as erratic readings (reactive EncoderMad).
    Now poll the AS5600 STATUS register (0x0B) at ~10 Hz and derive per-wheel
    "magnet properly in field" = MD set AND not too weak (ML) AND not too
    strong (MH). Surfaced as new fault bits (fb::MAG_L / MAG_R):
    - reported ALWAYS (bench alignment: visible even with use_encoders=0);
    - BLOCKING only when use_encoders=1 (so bench use_encoders=0 stays free).
    Shown on the Faults page and it lights the affected w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
    [control_types.hpp, controller_core.cpp, controller_core.hpp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]
2026-07-25 Telemetry: report 0 rpm/speed for a wheel whose encoder is in error
    When an encoder is in error the reported speed was garbage (e.g. a magnet
    out of field gave ~-272 rpm with nothing spinning). Now the published
    per-wheel rpm/speed falls back to 0 whenever that wheel's encoder is not
    trustworthy: absent, magnet out of field (AS5600 STATUS), or a latched
    encoder fault (stuck / reversed / erratic). speed_ms follows suit.
    Control is unchanged: it still uses the RAW measured sl/sr so the sanity
    checks can see and fault on the bad reading — only the telemetry/display
    is zeroed.
    Verified live: same bench with MAG_L active now reports rpm_l=0 instead of
    the erratic value. Host + 27 sim scenario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
    [controller_core.cpp]
2026-07-25 RPM = raw encoder-shaft speed; show it per wheel + m/s on the Faults page
    The rpm readout is now the ENCODER SHAFT speed (counts/s ÷ CPR × 60),
    independent of the gear ratio and of where the sensor sits in the drivetrain
    (gearbox output, 1:5 intermediate shaft, …) — so it's directly meaningful for
    bench-testing a gearbox. enc_rpm_per_cps drops the GEAR_RATIO factor; the
    vehicle speed (m/s) keeps its ratio-corrected conversion (unchanged).
    Faults page: the vehicle diagram now shows live readouts — each wheel's
    encoder rpm next to that wheel, and the final vehicle speed (m/s) at the
    center — updated every status frame. Dashboard bars relabeled
    "Left/Right encoder (rpm)".
    Verified: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
    [config_params.cpp, control_types.hpp, controller_core.hpp]
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2026-07-26 Encoders: reject RPM spikes (median-5) + shorter I2C timeout
    Live capture showed the raw rpm was ~1/3 corrupted — a clean ~950 rpm
    signal with wild ± sign-flip spikes (stdev 1313 on a 950 mean). Two
    causes, both addressed:
    - Delay→aliasing: the AS5600 is absolute 12-bit; the Δ wrap assumes < ½
    turn between reads. A stalled read let the shaft cross ½ turn (~30 ms at
    1000 rpm) → wrong-sign Δ. The per-read I2C timeout was 20 ms, so a bad
    read punched a huge hole. Cut to hw::I2C_XFER_TIMEOUT_MS = 4 ms.
    - Residual spikes (I2C corruption / EMI): 5-sample MEDIAN on the per-tick
    count rate before the EMA (controller_core). Median of clean data = clean
    (sim unchanged); it drops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
    [control_types.hpp, controller_core.cpp, controller_core.hpp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]
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2026-07-26 Encoder speed from real elapsed time, not a fixed 2 ms tick
    The count rate was Δcounts × CTRL_HZ, assuming every read is exactly 2 ms
    apart. But the encoder read sits after variable per-tick work (gamepad
    fetch, config copy) and FreeRTOS schedules on 1 ms boundaries, so the
    read-to-read spacing jitters — and the fixed multiplier turned that timing
    jitter into ~10% RPM ripple that the median/EMA couldn't remove.
    Now cps = Δcounts / actual_dt, where actual_dt is the esp_timer interval
    since the previous tick (guarded to nominal on the first tick or an absurd
    gap). Removes the read-spacing artifact; whatever ripple remains is real
    mechanical/open-loop wander. Sim-safe: the sim advances ti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
    [controller_core.cpp, controller_core.hpp]
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2026-07-27 WS2812: size RMT memory to the frame to stop 10-LED glitches
    The original ESP32 has no RMT DMA, so a strip is streamed from a 64-symbol
    memory block refilled by the RMT ISR mid-transmission. Two LEDs (48 symbols)
    fit in one block and are clean; ten (240 symbols) need refills, and a Wi-Fi/BT
    interrupt starving a refill underruns the stream → later LEDs latch random
    colours. Size the memory block to the frame (up to 256 symbols = 4 of the 8 RMT
    blocks) so ≤10 LEDs transmit in a single burst with no refill; longer strips
    still refill but in much larger chunks with far more ISR slack.
    [ws2812.cpp]
2026-07-27 Braking: open-loop brakes on release + freewheel option
    - Open-loop mode now engages DYNAMIC braking (motor short-circuit) when the
    stick is centered instead of coasting away, so releasing stops the kart like
    every other mode. Driving is still raw mixed-stick straight to the motors.
    - New `dyn_brake_en` param (default on): turn it off to FREEWHEEL — coast on
    release instead of dynamic braking — in both open and closed loop. The safety
    brake when disarmed / faulted / e-stopped is always on, independent of this.
    [config_params.cpp, control_types.hpp, controller_core.cpp]
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2026-07-27 Protobuf: typed enums for state/fault/brake_mode + typed oneof param values
    Make the WebSocket protocol self-describing instead of "everything is a float":
    - Status.state / .fault / .brake_mode are now proto enums (nested in Status so
    the generated C types Status_State/Fault/BrakeMode don't collide with the C++
    enum class of the same name). Wire stays varint, so the client is unaffected.
    - ParamVal and ParamMeta carry value / min / max / default as typed
    oneof { bool | int32 | float } matching the parameter's real type. The web
    form now renders a checkbox for a bool, an integer input for an int, a float
    input otherwise — no more guessing from a stringly-typed "type" field (dropp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
    [webserver.cpp]
2026-07-27 Cleanup: translate input_bp32.c, drop dead code, fix stale comments
    - Translate the remaining French comments in input_bp32.c to English (the last
    French file) and fix its outdated hook-signature comment.
    - Remove dead code: board::motorsStop, board::ledToggle (+ the write-only
    m_led_on), and the unused CMD_SET/CMD_VALS constants.
    - Fix comments that lagged behind refactors: config "everything is float" →
    typed CfgVal/CfgField union; turn_hi / turn-limit test linear-ramp → 1/v
    iso-a_lat; m_fwd_cmd "no smoothing"; input.hpp mixing moved to
    controller_core; u8x10 km/h → m/s; rpmU8 encoder-shaft rpm; rtos core
    attribution; config.cpp header; and drop GPIO4 from the "free GPIOs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
    [config_params.cpp, control_types.hpp, controller_core.hpp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]
2026-07-28 mDNS: reach the kart at http://kart.local instead of by IP
    Adds the espressif/mdns managed component (mDNS left ESP-IDF in v5) and a small
    mdns_svc module that publishes the "kart" host name plus the _http._tcp service
    on BOTH interfaces — SoftAP and station — so the same URL works whether you are
    on Kart-Config or on the home network, whose DHCP address kept changing.
    The same name is pushed to the router via esp_netif_set_hostname, so the kart
    shows up as "kart" in the DHCP client list, and it is reported in SysInfo
    (new proto field 23) so the System tab displays it as a clickable link.
    mDNS is a comfort feature: a start-up failure is logged and ignored, access by
    IP is never affecte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
    [main.cpp, webserver.cpp]
2026-07-28 Wi-Fi: refuse a save that would blank the password; document the gear ratios
    The Wi-Fi tab never re-fills the password field, so hitting Save without retyping
    it silently overwrote the stored one with an empty string — a working station
    config lost by touching an unrelated checkbox. The kart now refuses the save and
    says why, leaving NVS untouched; the page reports the outcome instead of claiming
    "Saved." before the answer even comes back.
    The floor is 8 characters, not merely non-empty: WPA2's minimum. A shorter key is
    accepted by every layer until the 4-way handshake drops it minutes later, and all
    you get is reason 15 in a log nobody is reading. That is exactly how this was
    found, so i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
    [webserver.cpp]
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2026-07-28 Drop two settings, show live battery voltage, finish the chain correction
    vbat_div_ratio and allow_reverse are gone from the settings table.
    The divider ratio was never a matter of taste — it is decided by the two resistors
    soldered to the board, and a wrong value silently misreports the pack and drags the
    LVC thresholds along with it. It is now hw::VBAT_DIV_RATIO, derived at compile time
    from VBAT_R_TOP and VBAT_R_BOTTOM so the formula, not a magic 7.667, is what is
    written down; swap the resistors and you edit the two values they name. Reverse is
    now unconditional, held back by rev_speed_ms as it always really was.
    Live voltage in two places. The Dashboard vehicle diagram shows the mea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
    [config_params.cpp, control_types.hpp, controller_core.cpp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]
2026-07-28 Add vbat_check_en, keep the fault LED blinking, switch the readouts to medians
    New setting vbat_check_en (Battery, default 1). At 0 the pack voltage is still
    measured, displayed and graphed, but stops being a driving condition: no fb::LVC,
    so nothing disarms and the 30 s power cutoff — which watches that very bit — never
    arms either. For bench work with nothing on the divider bridge. The battery's own
    BMS becomes the only protection against deep discharge, which the parameter help
    says outright. The low-battery orange on the LED strip is gated too: a bench with
    an open divider would otherwise sit permanently orange, which is the noise the
    option exists to remove.
    Proven in simulation ra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
    [config_params.cpp, control_types.hpp, controller_core.cpp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]
2026-07-28 LVC: judge a 2 s smoothed voltage, not the raw sag
    The 10.5 V cutoff is a lead-acid figure AT REST, and it was being thresholded
    against a reading taken UNDER LOAD. Roughly 20 A through ~0.05 Ω sags the pack
    about 2 V, so a perfectly healthy half-charged battery dips below the cutoff for
    about as long as an acceleration lasts — past the 500 ms debounce — and the kart
    cuts out mid-manoeuvre.
    Measured on the physics model, cutoff instant per pack:
    pack (12 V) expected raw τ1s τ3s τ5s τ10s
    healthy 12.8 V drives - - - - -
    half charge 12.0 V drives 5.5 ✗ - - - -
    low 11.5 V drives 5.5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
    [control_types.hpp, controller_core.cpp, controller_core.hpp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]
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2026-07-29 Two power rails, motor-power sense, encoder inversion, idle auto-off
    Four changes, all driven by the two-rail power architecture: the small opto relay
    module holds the LOGIC rail (ESP + motor board), the 40 A relay carries MOTOR
    power, and the emergency stop only has to cut the second one.
    That split is what makes the rest possible. The logic survives an e-stop, so the
    kart can say what happened instead of going dark — a feedback opto on the 40 A
    relay's output (GPIO34, input-only, active low so a broken wire reads "dead")
    tells the firmware whether motor power is live. With pwr_sense_en=1 it raises
    fb::NO_MOTOR_PWR, disarms, and needs a deliberate re-arm: releasing the mushroom
    button ne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
    [config.hpp, config_params.cpp, control_types.hpp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]
2026-07-30 Guard the protobuf arena at compile time; accept the e-stop freewheel
    The config overflowing the reply buffer should have been a build failure, not a
    dead WebSocket discovered by opening the page. It now is.
    nanopb can only emit a _size for messages without callbacks — Status (173 B) and
    SysDyn (29 B) get plain static_asserts. The config cannot be sized that way, since
    its params are callback-encoded, so the bound is computed where PARAMS actually
    lives: config_params.cpp walks the table at compile time, sums the wire cost of
    each entry's four strings and four typed oneofs, and asserts against
    hw::PB_REPLY_CAP. The file that grows when a parameter is added is now the file
    that refuses to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
    [config_params.cpp, control_types.hpp, webserver.cpp]
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2026-07-30 doc: real relay part numbers, and the capacitor belongs on the SMALL coil
    The two relays in hand are a TONGLING JQC-3FF-S-Z module (12 V, ~400 ohm, 30 mA,
    10 A contacts, opto in) for the logic rail and a YONGCHUAN YCL-12V-C automotive
    SPDT (12 V, ~80 ohm, 150 mA, 40 A on 87 / 30 A on 87a) for motor power. Feed the
    motors from 87, the NO contact that carries the 40 A rating; 87a is spare.
    Corrects where the hold capacitor goes. I had put it on the 40 A coil, reasoning
    only about motor power. With the small relay carrying the LOGIC rail that is
    wrong: if it drops mid-reboot the ESP loses its own supply and never comes back —
    a permanent shutdown, worse than a motor blip — and since the bi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
    [sim_main.cpp]
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

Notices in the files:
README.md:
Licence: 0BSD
